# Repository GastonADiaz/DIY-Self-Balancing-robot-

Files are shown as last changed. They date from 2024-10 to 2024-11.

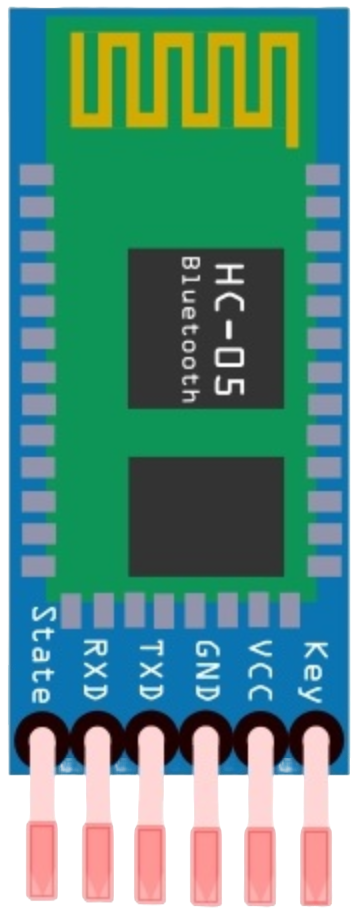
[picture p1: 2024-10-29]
4 - Imagenes para el repositorio/Componentes/hc05.png

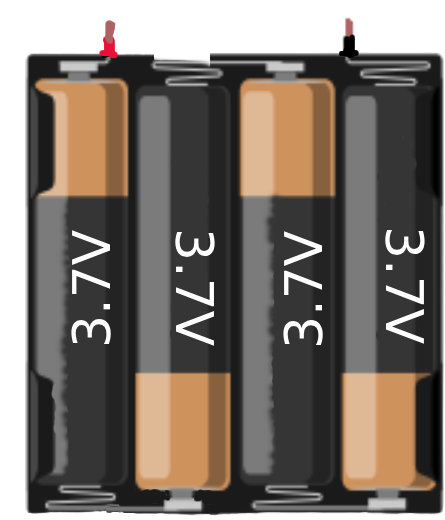
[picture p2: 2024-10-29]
4 - Imagenes para el repositorio/Componentes/4 pilas en serie.png

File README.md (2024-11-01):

# Table of Contents

- 📝 **1.0 [Introduction](#introduction)**
  - **1.1 [Team Members](#Team-Members)**
  - **1.2 [Overview and Objective](#overview-and-objective)**
  - **1.3 [Balancing Robot Working in Real Life](#balancing-robot-working-in-real-life)**
- ⚙️ **2.0 [Components Used](#components-used)**
  - **2.1 [List of Components](#list-of-components)**
  - **2.2 [Principal Tools](#principal-tools)**
  - **2.3 [List of Software Tools](#list-of-software-tools)**
- 🛠️ **3.0 [Mechanical Design](#mechanical-design)**
  -  **3.1 [3D Printed Parts](#3d-printed-parts)**
- ⚡ **4.0 [Electronics](#electronics)**
  -  **4.1 [Overview](#overview)**
  -  **4.2 [Circuit Diagram](#circuit-diagram)**
  -  **4.3 [Wiring Details](#wiring-details)**
  -  **4.4 [PCB Creation with EasyEDA](#pcb-creation-with-easyeda)**
- 💻 **5.0 [Important Code Explanations](#important-code-explanations)**
  - **5.1 [Arduino Nano Connection Pins](#arduino-nano-connection-pins)**
    - **5.1.1 [I2C](#i2c)**
    - **5.1.2 [Motor Driver Pins](#motor-driver-pins)**
  - **5.2 [Configuration](#configuration)**
  - **5.3 [Application Configuration](#application-configuration)**
- ❗ **6.0 [Troubleshooting](#troubleshooting)**
  -  **6.1 [Common Issues and Solutions](#common-issues-and-solutions)**
- 📈 **7.0 [Future Improvements](#future-improvements)**
  -  **7.1 [Potential Add-ons](#potential-add-ons)**
- 📚 **8.0 [Bibliography](#bibliography)**
- 🙏 **9.0 [Acknowledgments](#acknowledgments)**

# Introduction

## Team Members
<p>👤 <a href="https://github.com/GastonADiaz">Gastón Alejandro Díaz</a></p>
<p>👤 <a href="https://github.com/GuillermoDuarte888">Guillermo Daniel Duarte</a></p>

## Overview and Objective

This project addresses the challenge of building a self-balancing robot that maintains its stability in an upright position using two wheels. The robot is based on a series of components, including Nema 17 stepper motors, A4988 motor drivers, an MPU6050 gyro-accelerometer sensor, and an HC-05 Bluetooth module, all managed by an ATmega328p microcontroller.

Additionally, the project incorporates control of the robot via a mobile application. We use the EZ-GUI Ground Station app, typically employed for drones, but we utilize it to manipulate the self-balancing robot through a joystick interface and make custom configurations.

The central objective of this project is to implement a balance control system that allows the robot to remain upright on its own. To achieve this, the system utilizes feedback from the MPU6050 sensor, which measures the tilt angle or "pitch angle." Through a closed-loop control system with a PID (Proportional, Integral, and Derivative) controller, the robot adjusts motor speeds based on the measured angle, correcting any deviations and minimizing balance error. This approach enables the robot to dynamically adapt to variations and effectively maintain its stability.

We would also like to acknowledge the firmware "BalancingWii," which significantly assisted in the development of this project.

## Balancing robot working in real life

In the first video, the balancing robot is shown moving forward, backward, and turning. It is controlled using a mobile application (EZ-GUI Ground Station).

<p align="center">
  first video  
  <br />
  <i>First video in real life</i>
</p>

In the second video,you can see the balancing robot in action. It responds to an external force (in this case, my hands) and demonstrates its ability to maintain balance despite this disturbance. 

<p align="center">
  Second video  
  <br />
  <i>Second video in real life</i>
</p>

# Components Used

## List of Components

| Quantity | Component | Description |
|---|---|---|
| 7 | 3D Printed Parts | 2 wheels, 2 NEMA 17 motor mounts, 3 general structure parts, 4 light diffusers |
| 1 | Perforated Board | For electronics mounting |
| 2 | NEMA 17 Stepper Motors | Motor type used for the robot |
| 1 | MPU6050 | Gyroscope and accelerometer module |
| 2 | A4988 Drivers | Stepper motor drivers |
| 1 | ATmega328p (Arduino Nano) | Microcontroller |
| 1 | 7805T Voltage Regulator | Regulates voltage to 5V |
| 1 | 9V to 12V Power | Rechargeable battery or power supply |
| 1 | On/Off Switch | Power switch |
| 13 | Male Pins | For connecting stepper motor coils to the drivers and LEDs |
| 80 | Female Pins | For connecting various components |
| 1 | 2-Pin Terminal Block | For power connection |
| 2 | Heat Sinks | For cooling the A4988 drivers |
| 2 | 100µF Capacitors | 16V capacitors |
| 2 | 220µF Capacitors | 16V capacitors |
| 8 | XH2.54 Connectors | 2 connectors with 4 pins and 2 connectors with 6 pins for stepper motor wiring |
| 1 | 1 Meter M8 Threaded Rod | For structural support |
| 24 | M8 Hex Nuts | For threaded rod connections |
| 12 | M4 Hex Nuts | For securing components to the structure |
| 12 | M4 Phillips Head Bolts (13mm) | For mounting motor supports and electronics board |
| 8 | M3 Phillips Head Bolts (8mm) | For securing stepper motor mounts |
| 2 | GND and Vin Cables | Power supply cables for the entire circuit |
| 1 | HC-05 Bluetooth Module | For mobile application control |
| 10 | Heat Shrink Tubing | For soldering and joining wires |
| 4 | Green LEDs | For indicating status |
| 4 | 220Ω Resistors | For current limiting on the LEDs |
| 3 | 1kΩ Resistors | For voltage division to provide 3.3V to the RX pin of the HC-05 |
| 4 | Cable Ties | For securing cables |

## Principal Tools

| Quantity | Tool | Description |
|---|---|---|
| 1 | Soldering Iron | For soldering connections |
| 1 | Desoldering Pump | For removing solder |
| 1 | Multimeter (Tester) | For measuring voltage and continuity |
| 1 | Solder wire | For making electrical joints |
| 1 | Screwdriver | For fastening screws |

## List of Software Tools

| Software | Description |
|---|---|
| SolidWorks 2023 | I used SolidWorks 2023 to design the 3D printed parts, model various components, and utilize its toolbox for bolts, nuts, etc. |
| Wokwi | I used Wokwi to create and simulate electronic schematics and code, with the added benefit of simulating without needing physical connections. |
| Arduino IDE | I used Arduino IDE to write and upload the code to the ATmega328p microcontroller. |
| Easy Eda Designer | I used Easy Eda Designer for PCB creation and electronic schematics, as it is a very tidy software for designing PCBs. It allows exporting traces for PCB milling or sending the Gerber file for manufacturing. |
| EZ-GUI Ground Station | I used the EZ-GUI Ground Station APK for mobile control of the robot, allowing manipulation through a joystick interface. |

# Mechanical Design

In this section, I will describe the mechanical design of the robot, including the 3D printed parts and the overall assembly. The designs were created using SolidWorks 2023, which allowed me to visualize the dimensions needed and plan the hardware required, such as screws and other components. The toolbox in SolidWorks also helped in determining the quantity of parts needed and in assembling the pieces to see how everything fits together.

<p align="center">
  All Parts
  <br />
  <i>3D printed parts</i>
</p>

### 3D Printed Parts

1. **Base Plate of the Structure**<br />
  This part is designed to be the base of the balancing robot. It connects with the stepper motors and features 6 holes on each side for screws to secure the NEMA 17 motor mounts. Additionally, there are 4 holes for the 8mm threaded rod that supports the structure.

2. **Support for the NEMA 17 Stepper Motors**<br />
  This piece functions similarly to metal brackets for NEMA 17 motors. However, by printing it, we reduce costs while maintaining the same efficiency for our project. It also includes 2 extra holes compared to standard brackets, allowing for more secure mounting with up to 6 screws.

3. **Central Plate of the Structure**<br />
   This part includes 4 holes for the 8mm threaded rod and 4 additional holes to mount the electronic board. It serves as a key component in securing the electronics in place.

4. **Upper Plate of the Structure**<br />
   This piece is designed to be the top of the robot’s structure. It has 4 holes for the 8mm threaded rod and is a simple yet essential part of the assembly, providing the top support for the robot.
   
5. **Wheels** <br />
   These are the wheel designs used for the robot. Initially, another type of wheel was planned, but this design was chosen for better performance and suitability for the project.

6. **Light Diffusers**  
   The light diffusers are designed to illuminate a LED and are shaped like arrows to indicate the direction of the motor wheels. When both wheels rotate clockwise, the LED will point forward, and when both wheels rotate counterclockwise, the LED will point backward.
   
### Assembly of the Balancing Robot  
   This image shows the overall assembly created in SolidWorks. It combines all the 3D printed parts, demonstrating how they fit together and providing a complete view of the robot's mechanical structure.

<p align="center">
  All Parts  
  <br />
  <i>Rendered in SolidWorks with PhotoView 360</i>
</p>

<p align="center">
  
  <br />
  <i>Assembly animation made with SolidWorks</i>
</p>

# Electronics

## Overview

In this section, I will describe the electronics used in the project. I utilized [Wokwi](https://wokwi.com/) to present the schematic in a more legible and understandable format for anyone. EasyEDA was primarily used to visualize the PCB design, which helped in understanding how the soldering would look and in planning the location of components

## Circuit Diagram

I used Wokwi to create a clear and easy-to-understand schematic diagram. Below is the schematic created using Wokwi (As not all the components are in Wokwi, I had to add it with [photopea](https://www.photopea.com/)):

<p align="center">
  Circuit Diagram
  <br />
  <i>Wokwi connection diagram</i>
</p>

## Wiring Details

The following details explain the purpose of each color used in the wiring connections:

- 🔴 **Red**: Represents the 5V output pin from the ATmega328p.
- ⚫ **Black**: Represents GND.
- 🔵 **Blue**: Represents the microstep pins (MS1, MS2) of the A4988 stepper motor drivers.
- 🟢 **Light Green**: Represents signals from the ATmega328p to control motor steps and direction (STEP and DIR pins of the A4988).
- 🌲 **Dark Green**: Represents a bridge from the SLEEP and DIR pins of the A4988 driver; also used for the positive signal to the LEDs.
- 🌫️ **Gray**: Represents the stepper motor coils (1A, 1B, 2A, 2B).
- 🟦 **Cyan**: Represents I2C communication for the MPU6050.
- 🟠 **Orange**: Represents the power supply (7V, up to 35V).
- 🌸 **Magenta**: Represents 5V output from the 7805T voltage regulator.
- 💛 **Yellow**: Represents the ENABLE pin of the A4988.
- ⚪ **White**: Represents the RX and TX pins of the HC-05.

## PCB Creation with EasyEDA

First, I used **[EasyEDA Designer](https://easyeda.com/es)** to create the overall schematic, connecting the pins of the respective components with their labels to make it more readable. I divided the design into three parts:

1. **Power Supply**: This section includes the circuit necessary to power the Arduino through the **Vin** port, supplying it with 5V.
   
2. **Arduino Nano**: Here, you can find the labels and pins used for the Arduino Nano.

3. **Other Modules**: In the third section, we can see other modules such as the **HC-05**, **MPU6050**, **A4988**, and some male pins that will be used on the board.

<p align="center">
  Esquematico General
  <br />
  <i>Main schematic</i>
</p>

Next, we move on to the PCB creation, where we place the components' locations and the soldering paths for better organization when creating it in real life. In the following image, we can see the soldering paths from the top view (Red color 🔴)  as well as the bottom view (Blue color 🔵). There are also measurement dimensions in case anyone is interested in replicating it.

<p align="center">
  PCB Full
  <br />
  <i>PCB with measurements and both solder paths fused</i>
</p>

Finally, here is how a printed circuit board would look, both from the top and bottom views. I did not include 3D components because I prefer to show the silkscreen.

<p align="center">
  PCB_Superior_e_Inferior
  <br />
  <i>PCB Top and Bottom View</i>
</p>

In the following GIF, you can see the components and the 3D PCB layout that were created in EasyEDA. It also features functionalities such as changing the color of the board and the option to hide or show the components, among other capabilities. This representation is essentially our actual board, but with a perforated design.

<p align="center">
  PCB en vista 3D
  <br />
  <i>PCB visualized in 3D with EasyEDA</i>
</p>

# Important code explanations

## Arduino Nano Connection Pins

### I2C:
- A4 - SDA
- A5 - SCL

```
#define I2C_PULLUPS_ENABLE         PORTC |= 1<<4; PORTC |= 1<<5;   // PIN A4 & A5 (SDA & SCL)
```

### Motor Driver Pins:
- D5 - STEP1 (PORTD 5)
- D6 - STEP2 (PORTD 6)
- D7 - DIR1 (PORTD 7)
- D8 - DIR2 (PORTB 0)
- D4 - ENABLE (for both)
  
```
uint8_t DRIVER_PIN[5] = {5, 6, 7, 8, 4};   // STEP1 (PORTD 5), STEP2 (PORTD 6), DIR1 (PORTD 7), DIR2 (PORTB 0), ENABLE
```
## Configuration

These are the optional settings you can modify for each balancing robot in the `config.h` file:

The first important configuration is the orientation of the MPU6050. You can change this in this section by setting it to either "ROLL" or "PITCH." In my case, I use "PITCH."

```
#define CURRENT_AXIS    PITCH       // it is possible to choose ROLL or PITCH axis as current.
```

Another crucial setting for the balancing robot is the adjustment of values based on its performance. Comments indicate typical values that usually work well:

```
#define MAX_SPEED           350    // should be <= 500 // Con 350 va bien 
#define MAX_TARGET_ANGLE    130    // where 10 = 1 degree, should be <= 15 degree (i.e. <= 150) 
#define MAX_STEERING        90     // should be <= 100

#define RISE_SPEED_K        1.0f   // this coefficient means how faster robot will be during the auto rising...  should be >= 0.5 but <= 2.0
```

Another configuration pertains to the HC-05 Bluetooth module. To use it, it must be set to a baud rate of 115200, as shown in the following lines of code:

```
#define SERIAL0_COM_SPEED 115200
#define SERIAL1_COM_SPEED 115200
#define SERIAL2_COM_SPEED 115200
#define SERIAL3_COM_SPEED 115200
```

By default, Bluetooth modules come configured to 9600 baud. To change this, you need to enter the following command in the serial terminal while the module is in AT mode :
```
AT+UART=115200,0,0
```
If for any reason you need to modify how the left and right motors are managed, you can do so in the Interrupt Service Routine (ISR) located in `Output.cpp`. This ISR is responsible for controlling the STEP and DIR signals for both motors.

The ISR is defined as follows:
```
ISR(TIMER1_COMPA_vect) {
}
```

# Application Configuration

As mentioned in another section of this README, we will be using the [EZ-GUI Ground Station application](https://ez-gui-ground-station.uptodown.com/android), which can be downloaded from Google .

The first time you install the application, it will prompt you to enable Bluetooth and location services; make sure to allow both.

<p align="center">
  Primera imagen Ez-Gui
  <br />
  <i>first steps to follow</i>
</p>

Once that is done, go to the three dots in the upper right corner and select "Settings." In this section, choose the Bluetooth module HC-05. After selecting it, click the "Next" button.

Next, select the "Multiwii 2.40" firmware from the list and keep clicking "Next" until you reach the home screen.

Once everything is configured, click the "Connect" button. After connecting, swipe the screen to the right to see the following:

<p align="center">
  Menu de opciones
  <br />
  <i>options menu</i>
</p>

Then, press the "AUX" option and check all the boxes in the following settings. After doing this, click the upload button (the red arrow pointing upwards).

<p align="center">
  AUX
  <br />
  <i>AUX option</i>
</p>

Next, go back and click on the "PID" button. I recommend using the following values if you are using the same design and wheels as I am, as each robot behaves differently. A smaller robot might require different PID values, just as a larger robot with bigger wheels would.

As before, upload the values to the Arduino using the red arrow button.

<p align="center">
  PID
  <br />
  <i>PID option</i>
</p>

The last option is for calibrating the MPU6050. For this, the wheels of your balancing robot must be stationary, and the robot should be perfectly vertical on a flat surface. When you press the "Calibration" button, wait about 10 to 15 seconds for it to complete the gyroscope and accelerometer calibration process.

Finally, you can start using your balancing robot by going back from this screen, clicking on the three dots in the top right corner, selecting "Advanced," then "Untested," and finally clicking on "Model Control."

<p align="center">
  joystick
  <br />
  <i>joystick</i>
</p>

>[!NOTE]
>To stop the wheels, use [MID] in the first option. Use [ARM] to turn the wheels on.

In the third option, you can also experiment with the different settings available in the application, and you have the joystick to control the balancing robot.

# Troubleshooting

## Common Issues and Solutions

**1. Wheel Slipperiness:**
   
One of the main challenges encountered in this project was related to the wheels. The 3D-printed wheels were very slippery on certain surfaces, such as ceramic and wood.

**Solution:**
To enhance grip and friction, we added strips of EVA rubber around the entire perimeter of the wheels. This significantly improved the wheel's traction on slippery surfaces.

<p align="center">
  
  <br />
  <i>wheels with EVA rubber</i>
</p>

**2. Wheel Attachment Stability:**
   
Another issue with the wheels was that the screws used to attach them were insufficient. Over time, vibrations from the motor caused the screws to loosen and come out.

<p align="center">
  
  <br />
  <i>After a long time, the wheels would gradually come off due to the vibrations of the motors.</i>
</p>

**Solution:**
To resolve this, we applied adhesive to secure the axle parts. This greatly improved stability, and the wheels no longer detached.

**3. A4988 Driver Potentiometer Adjustment:**

Another issue was related to the potentiometer on the A4988 driver. When set to a low level (around 0.2V), the wheels would barely move, especially under load.

**Solution:**
By adjusting the potentiometer to approximately 1V, we found that both wheels operated smoothly, resolving the issue of the wheels stalling when they encountered resistance. This adjustment made a significant difference in performance.

<p align="center">
  
  <br />
  <i>Adjustment of the A4988 driver potentiometer</i>
</p>

**4. Bluetooth Module Connection During Upload:**

When uploading code to the Arduino Nano, the Bluetooth module must be disconnected. This is necessary because the module uses the RX and TX pins of the Arduino for communication.

**Solution:**
When you upload code, the Arduino needs exclusive access to the RX (receive) and TX (transmit) pins to communicate with the computer. If the Bluetooth module is connected, it may interfere with this process, preventing the upload from completing successfully. To ensure a smooth upload, always disconnect the Bluetooth module before loading new code onto the Arduino Nano.

# Future Improvements

##  Potential Add-ons

I. **18650 Battery Power Source:**
   Incorporating 18650 batteries as a power source could enhance the robot's mobility. In my case, I currently use a 12V power supply, as the batteries are quite expensive in my country. The batteries would allow for greater freedom of movement without the risk of cables tangling during turns.

II. **Camera Integration:**
   Adding a camera to the balancing robot would enable remote observation, as if the robot were exploring areas. This feature could facilitate mapping of environments.

III. **Ultrasonic Sensor Module:**
   Integrating an ultrasonic sensor would help the robot avoid collisions with walls or obstacles, enhancing its navigation capabilities.

IV. **Improved Printed Circuit Board (PCB):**
   While I initially used a perforated board, there are PDF files available for creating a more professional-looking PCB using either the marker or toner transfer methods. Additionally, you could consider sending the design to a manufacturer like PCBWay or other reputable providers.

V. **Custom Software Development:**
   Creating a complete application and software from scratch, without relying on existing libraries or pre-made applications, would be a significant undertaking. However, the current setup provides a solid foundation for such an endeavor.

# Bibliography

All the references used in the development of this project will be compiled in a text file, which will include all the links we utilized as guides throughout the process.

# Acknowledgments

I would like to extend my sincere gratitude to several individuals and organizations for this project.

- **Guillermo Daniel Duarte**: A special thank you to my colleague for his invaluable assistance and support throughout this project. Your help was crucial to its completion.

- **Professor Cristian Leandro Lukasiewicz**: I am deeply grateful to Professor Lukasiewicz for overseeing our Supervised Professional Practice (PPS) and providing guidance and support throughout the process.

- **National University of Lomas de Zamora, Faculty of Engineering**: For opening the doors to a rich academic environment that has allowed me to pursue my studies and acquire valuable knowledge.

- **Mahowik**: A heartfelt thanks to Mahowik for the fantastic firmware provided in the [BalancingWii](https://github.com/mahowik/BalancingWii). Your work has greatly contributed to the success of this project.

- **To all readers**: I hope you find this project both interesting and useful.

Logo facultad con color

<div align="center">

<b><i>Best regards, and have a great day!</i></b>

</div>

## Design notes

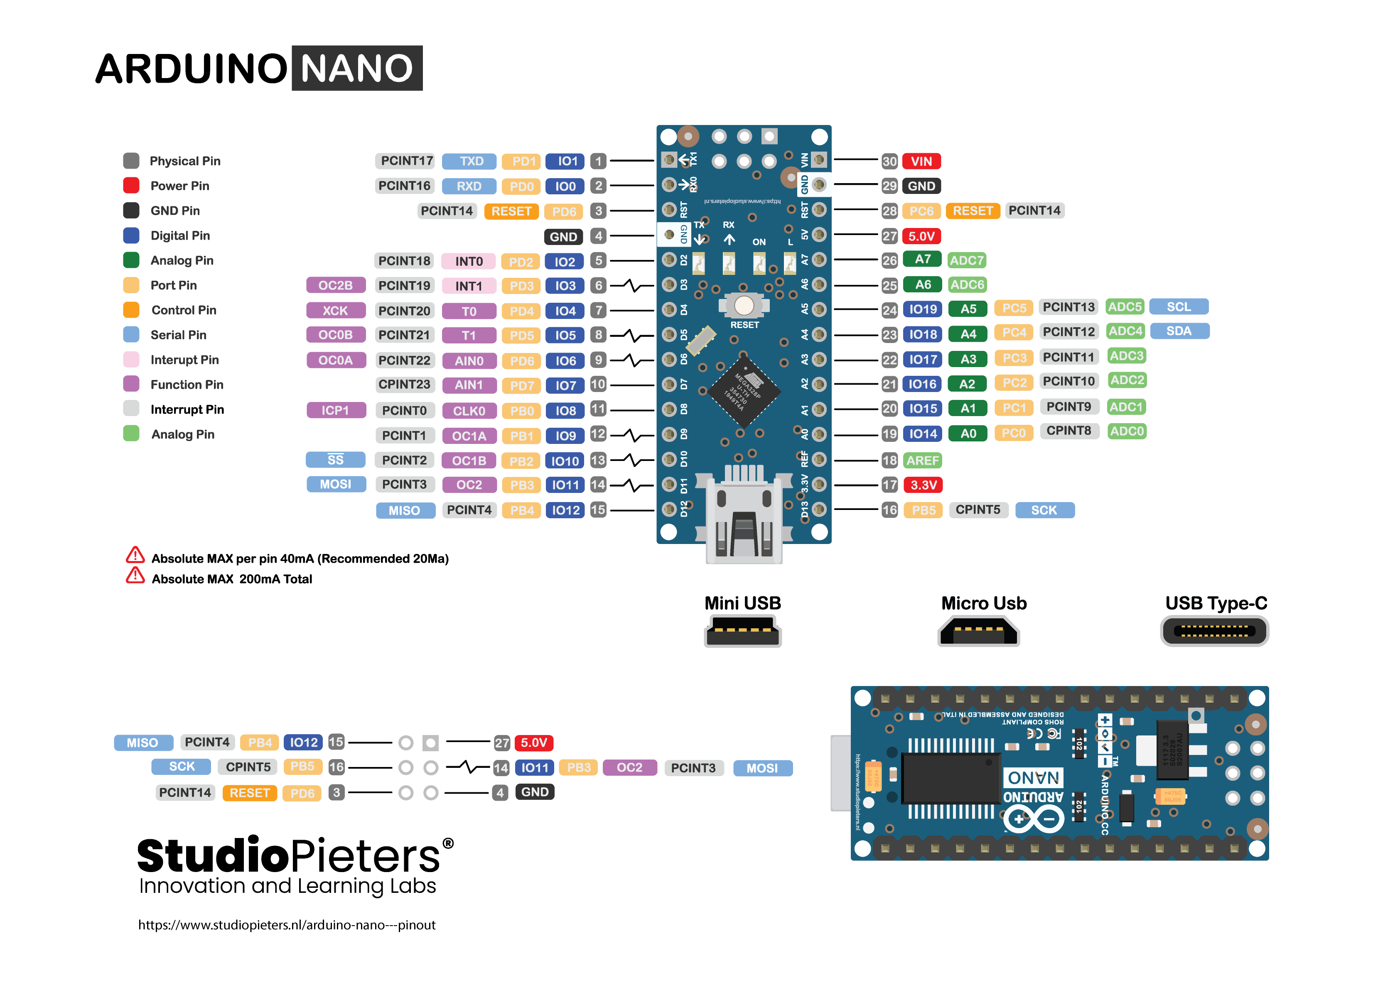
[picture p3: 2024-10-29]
4 - Imagenes para el repositorio/Componentes/Arduino-Pinout.png

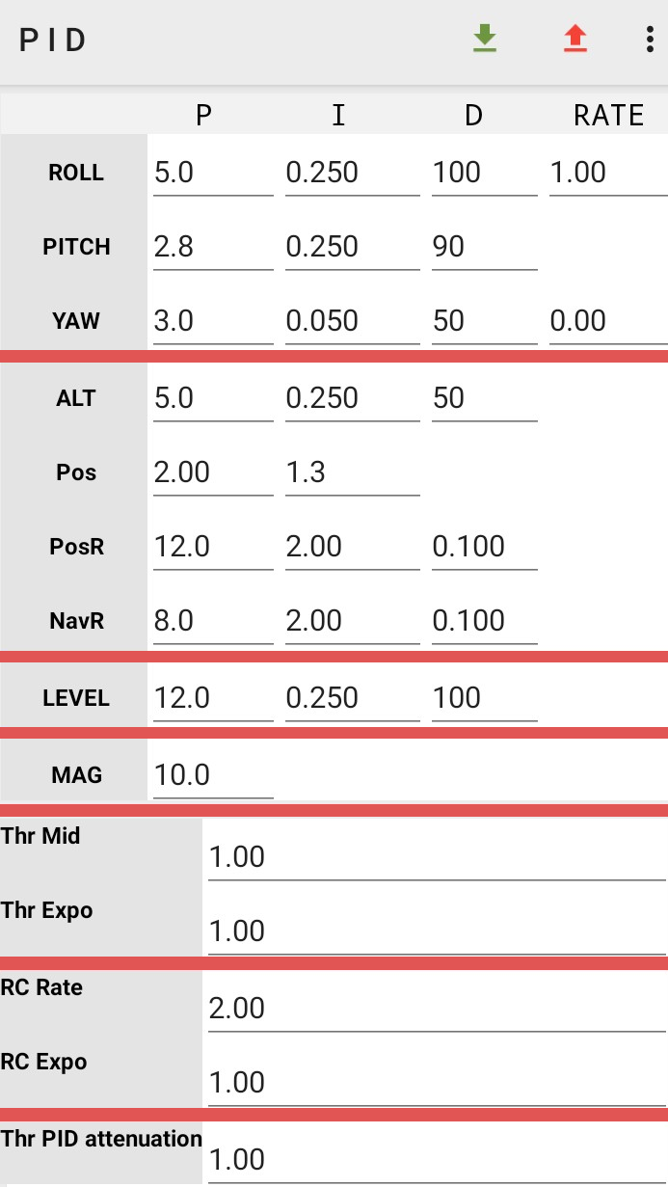
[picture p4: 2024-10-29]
4 - Imagenes para el repositorio/PID.png

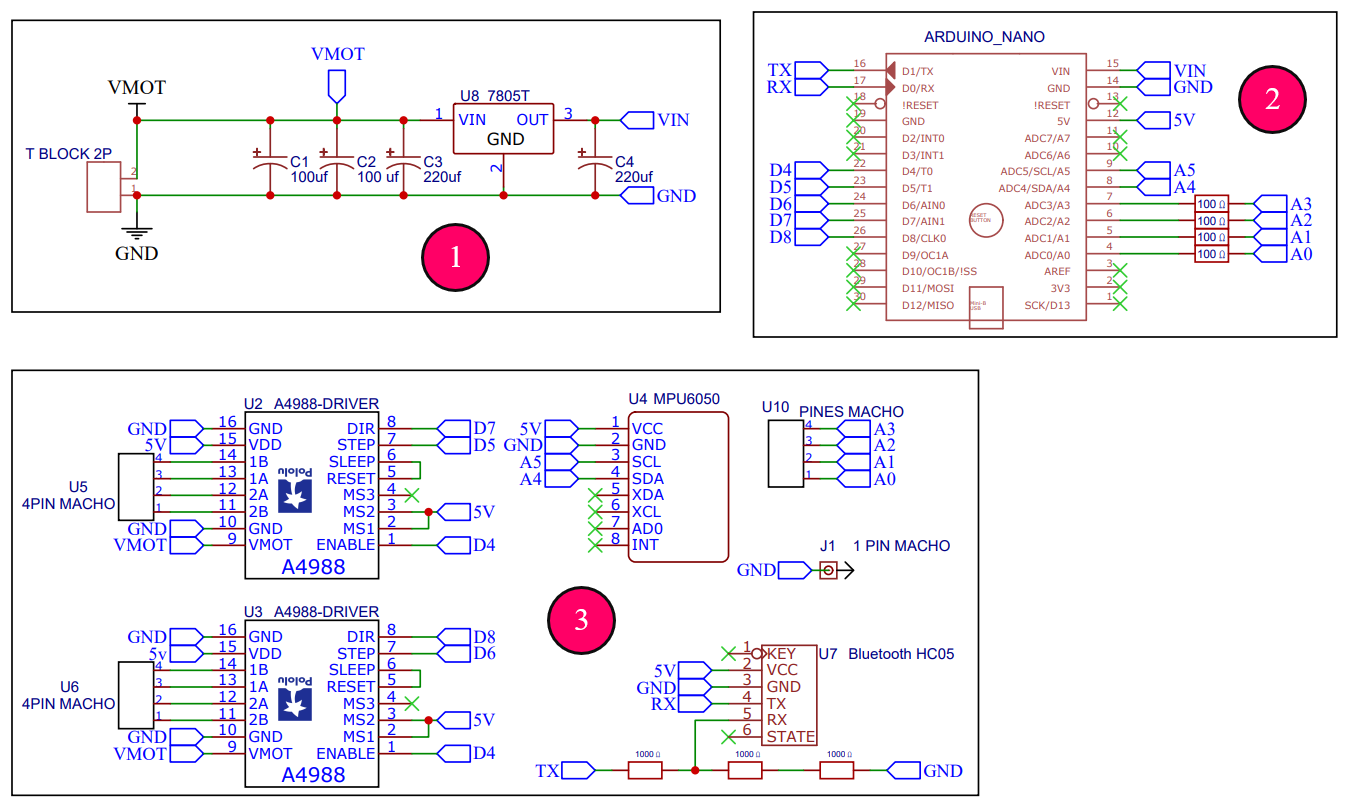
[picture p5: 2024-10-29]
4 - Imagenes para el repositorio/Esquematico_General (1).png

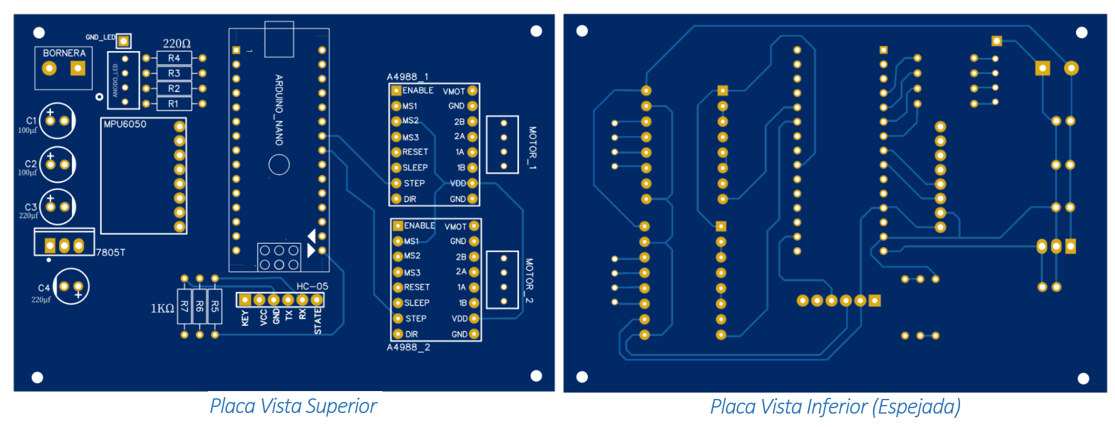
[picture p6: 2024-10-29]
4 - Imagenes para el repositorio/Placa Vista Superior e Inferior.png

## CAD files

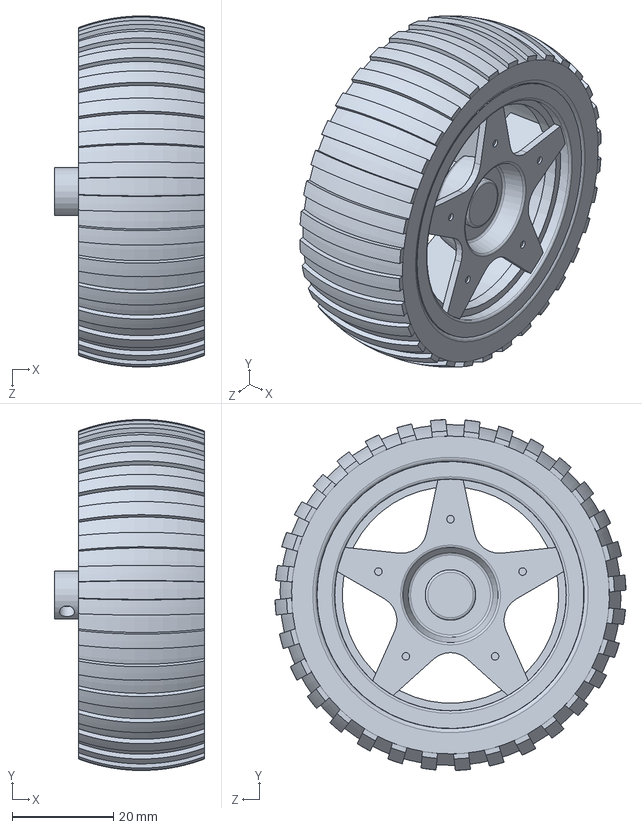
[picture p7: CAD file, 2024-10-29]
1 - Piezas solidworks/Ensamblaje de Rueda.SLDPRT
29.8 x 69.5 x 69.5 mm

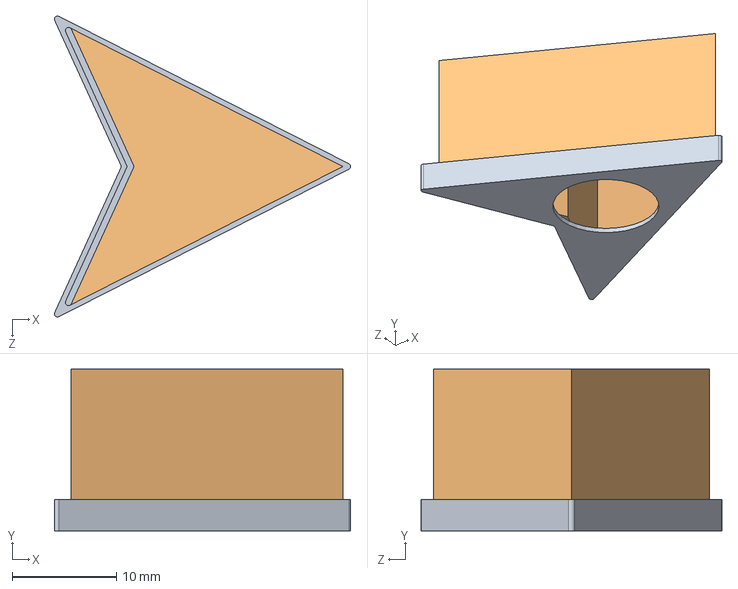
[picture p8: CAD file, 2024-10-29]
1 - Piezas solidworks/Ensamblaje para difusor de luz.SLDASM
28.4 x 15.5 x 28.8 mm
Pieza11 - Difusor de luz 20mm
Pieza12 - Encaje difusor de luz 20mm

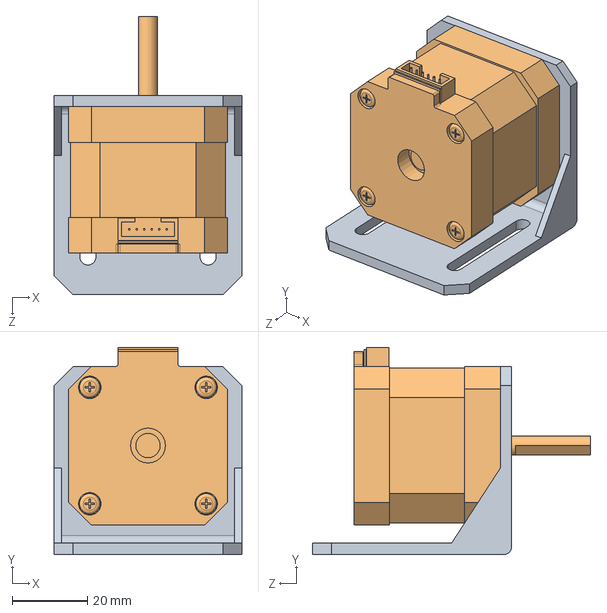
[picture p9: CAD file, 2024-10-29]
1 - Piezas solidworks/Ensamblaje Motor nema 17 con soporte.SLDASM
50.0 x 55.1 x 74.0 mm
Pieza 4 - Soporte de motor paso a paso Nema 17
Pieza 5 - Motor paso a paso Nema 17

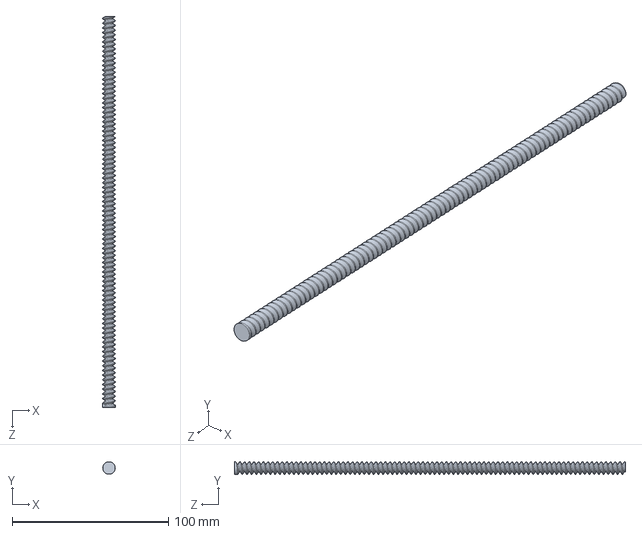
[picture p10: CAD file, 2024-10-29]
1 - Piezas solidworks/Pieza 6 - Varilla roscada.SLDPRT
8.00 x 8.00 x 250.0 mm

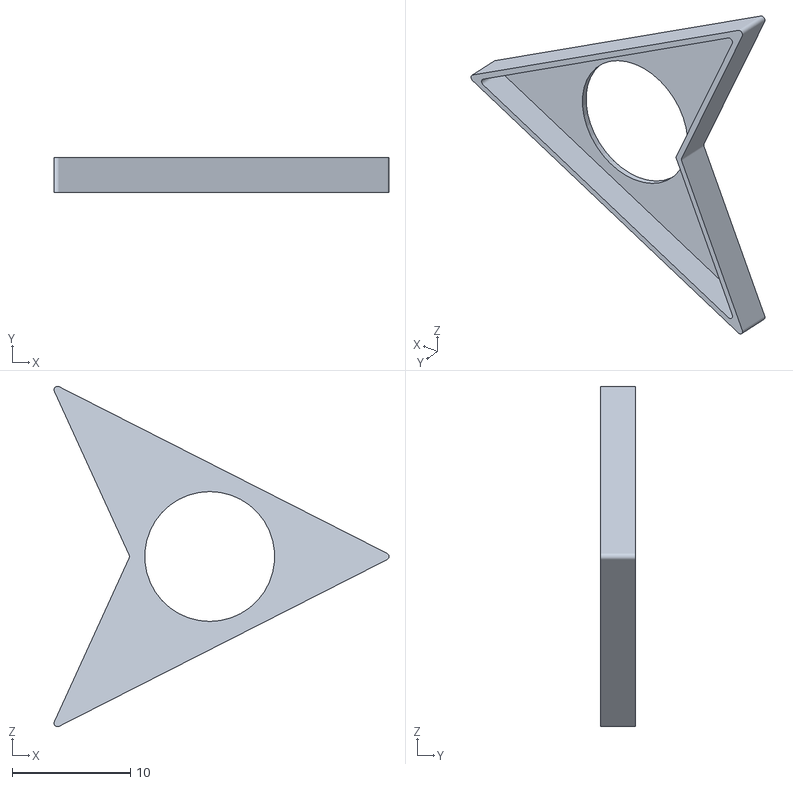
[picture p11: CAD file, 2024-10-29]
1 - Piezas solidworks/Piezas para imprimir/Piezas en STL/Pieza12 - Encaje difusor de luz 20mm.STL
28.4 x 3.00 x 28.8

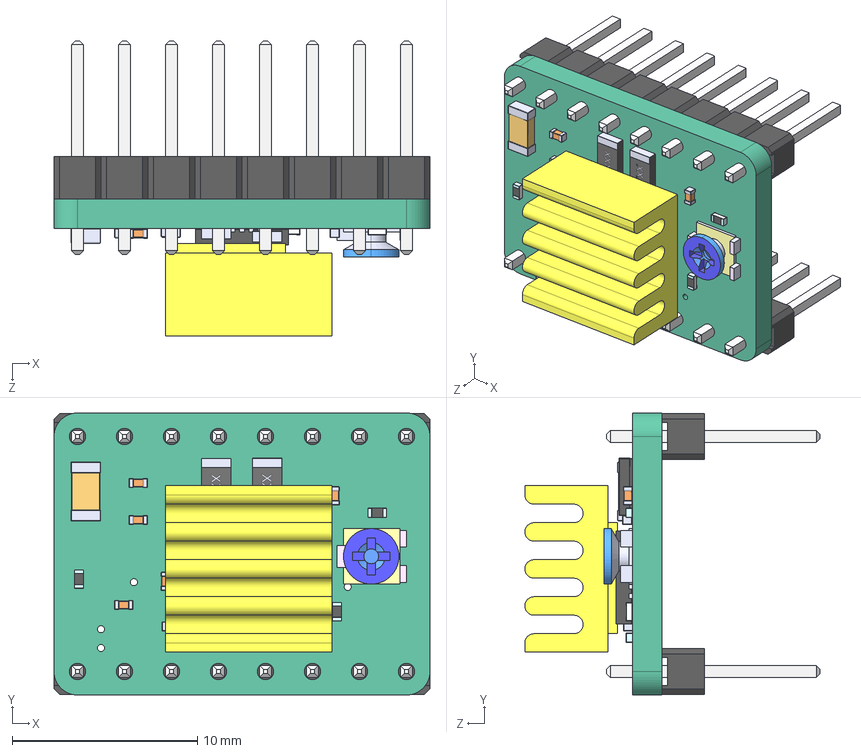
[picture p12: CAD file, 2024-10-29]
2 - PCB en proteus (Para ESP32S)/apariencias para proteus/A4988-1.STEP
20.3 x 15.2 x 16.0 mm
stepstick
QFN28ET_A4983
TRIMPOT3MM_TRIMPOTSMD
Pin header pitch 2.54mm_08 contacts x 2
Heatsink For A4988
R0402-01 x 4
R1206-01 x 2
C0402 x 6
C1206B

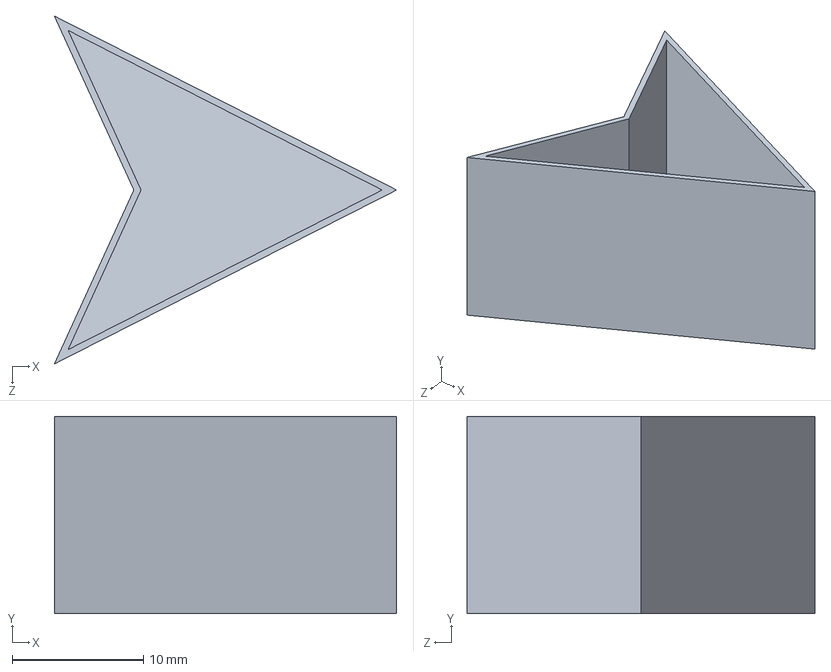
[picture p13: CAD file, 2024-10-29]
1 - Piezas solidworks/Pieza11 - Difusor de luz 20mm.SLDPRT
26.0 x 15.0 x 26.5 mm

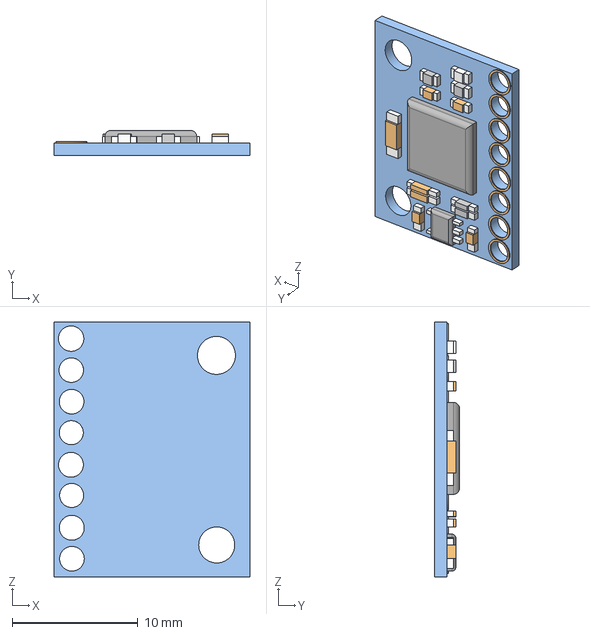
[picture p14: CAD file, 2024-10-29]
2 - PCB en proteus (Para ESP32S)/apariencias para proteus/MPU6050 v2.step
15.6 x 2.00 x 20.3 mm

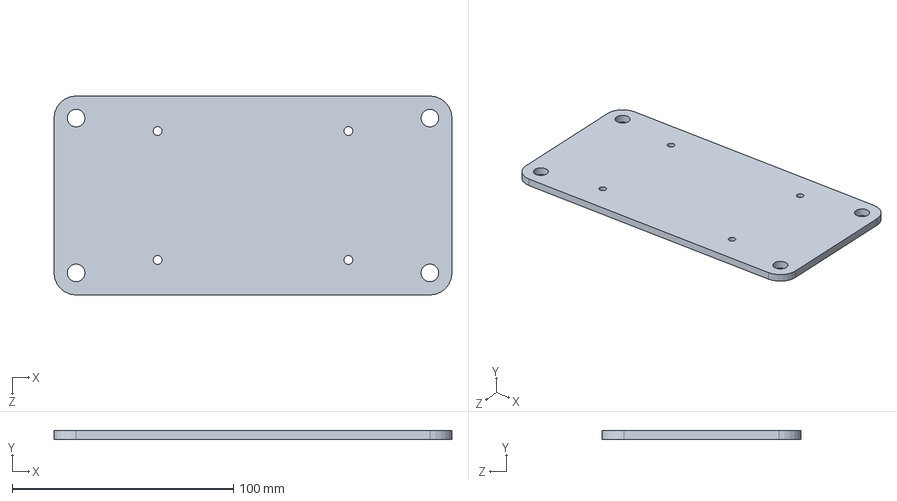
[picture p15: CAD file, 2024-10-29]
1 - Piezas solidworks/Pieza 7 - Placa central de la estructura general.SLDPRT
180.0 x 4.00 x 90.0 mm

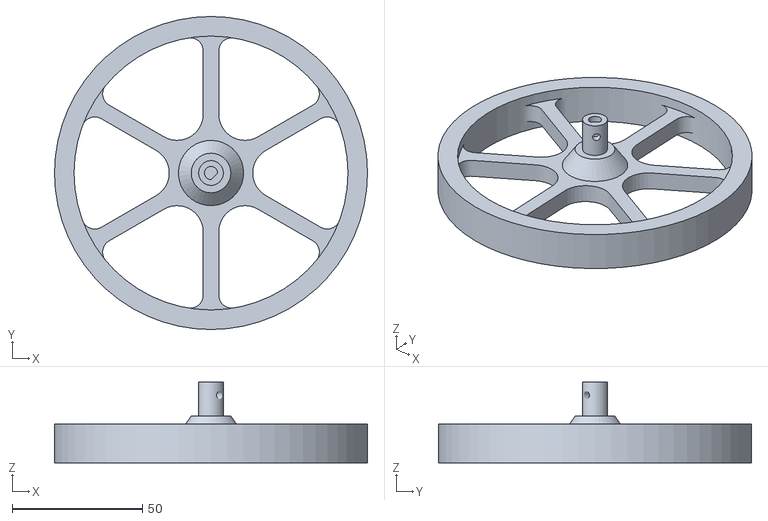
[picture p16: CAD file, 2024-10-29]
1 - Piezas solidworks/Piezas para imprimir/Piezas en STL/Pieza 10 - Rueda simple.STL
120.0 x 120.0 x 31.0

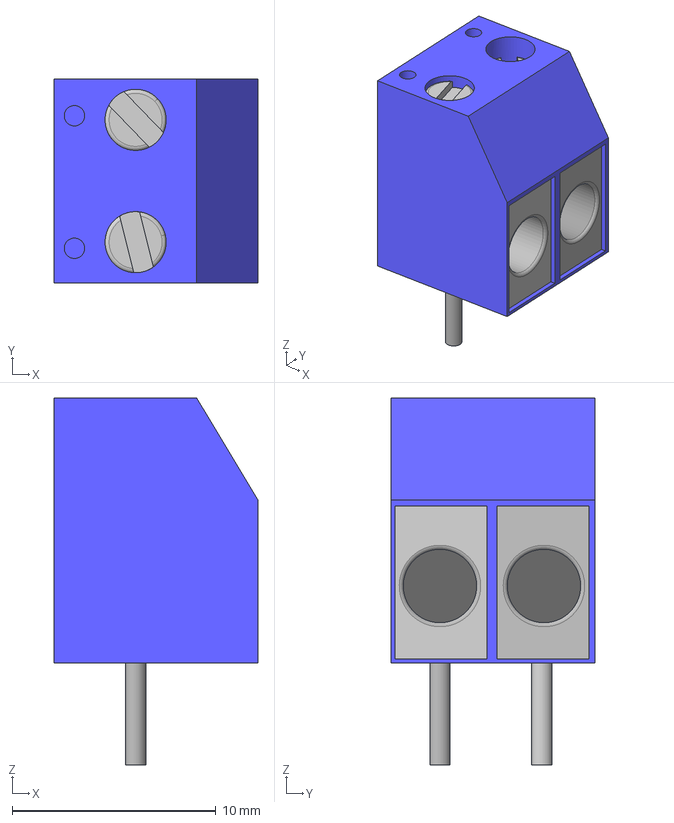
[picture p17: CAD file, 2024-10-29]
2 - PCB en proteus (Para ESP32S)/apariencias para proteus/borneraazul2pines.step
10.0 x 10.0 x 18.0 mm

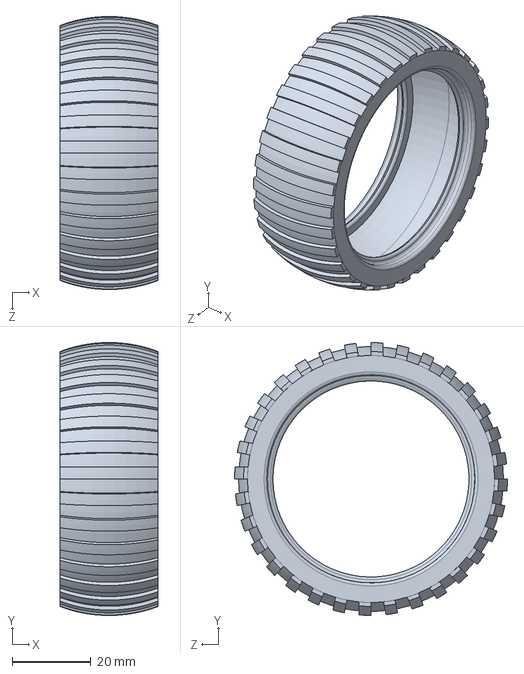
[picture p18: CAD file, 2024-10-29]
1 - Piezas solidworks/Pieza 3 - Goma de rueda.SLDPRT
25.0 x 69.5 x 69.5 mm

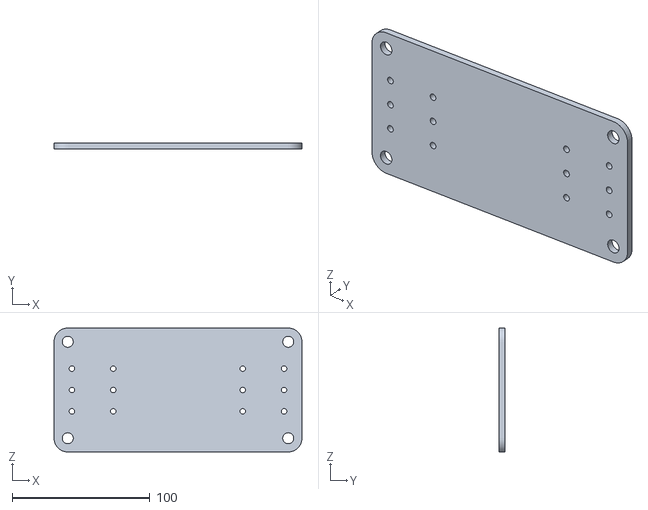
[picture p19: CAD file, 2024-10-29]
1 - Piezas solidworks/Piezas para imprimir/Piezas en STL/Pieza 1 - Placa inferior de la estructura general.STL
180.0 x 4.00 x 90.0

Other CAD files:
1 - Piezas solidworks/Piezas para imprimir/Piezas en STL/Pieza11 - Difusor de luz 20mm.STL
1 - Piezas solidworks/Pieza 9 - Placa superior de la estructura general.SLDPRT
1 - Piezas solidworks/Piezas para imprimir/Piezas en STL/Pieza 7 - Placa central de la estructura general.STL
1 - Piezas solidworks/Pieza12 - Encaje difusor de luz 20mm.SLDPRT
1 - Piezas solidworks/Piezas para imprimir/Piezas en STL/Pieza 9 - Placa superior de la estructura general.STL
1 - Piezas solidworks/Pieza 0 - Piso.SLDPRT
1 - Piezas solidworks/Pieza 1 - Placa inferior de la estructura general.SLDPRT
1 - Piezas solidworks/Pieza 10 - Rueda simple.SLDPRT
1 - Piezas solidworks/Pieza 2 - Rin de rueda.SLDPRT
1 - Piezas solidworks/Pieza 4 - Soporte de motor paso a paso Nema 17.SLDPRT
1 - Piezas solidworks/Pieza 5 - Motor paso a paso Nema 17 .SLDPRT
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

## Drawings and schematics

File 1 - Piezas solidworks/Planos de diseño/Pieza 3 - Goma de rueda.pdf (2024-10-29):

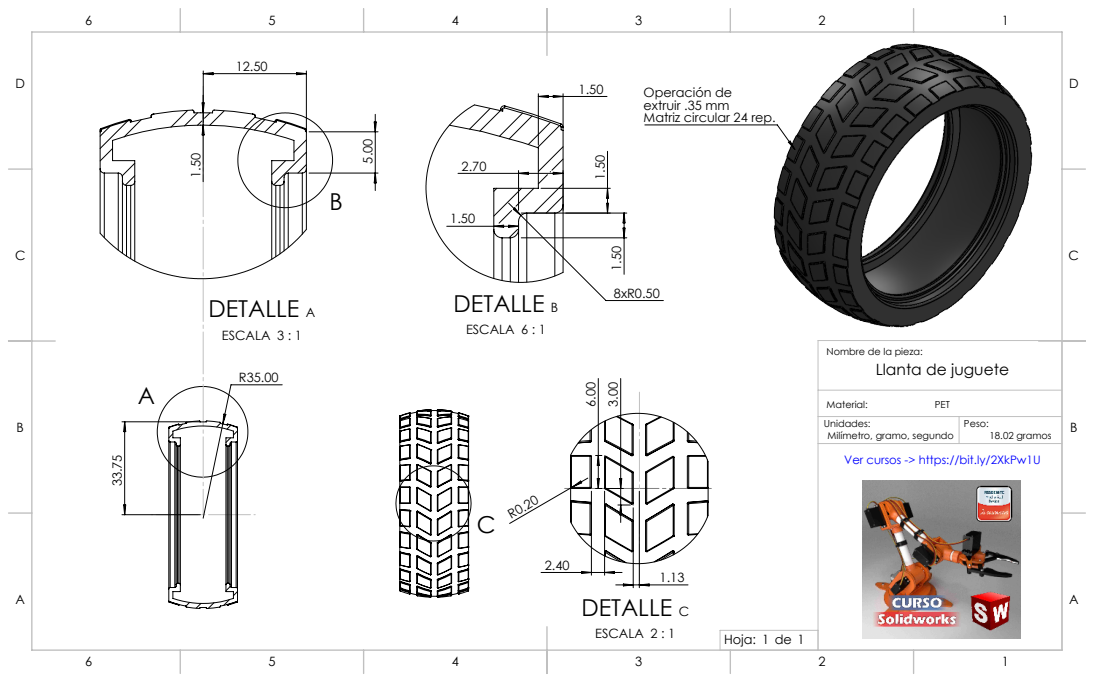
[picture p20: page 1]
DETALLE A; ESCALA 3 : 1; 8xR0.50 DETALLE B; ESCALA 6 : 1; DETALLE C; ESCALA 2 : 1; 18.02 gramos; Hoja: 1 de 1

Operación de
extruir .35 mm
Matriz circular 24 rep.

Nombre de la pieza:
Llanta de juguete

Milímetro, gramo, segundo
Ver cursos -> https://bit.ly/2XkPw1U

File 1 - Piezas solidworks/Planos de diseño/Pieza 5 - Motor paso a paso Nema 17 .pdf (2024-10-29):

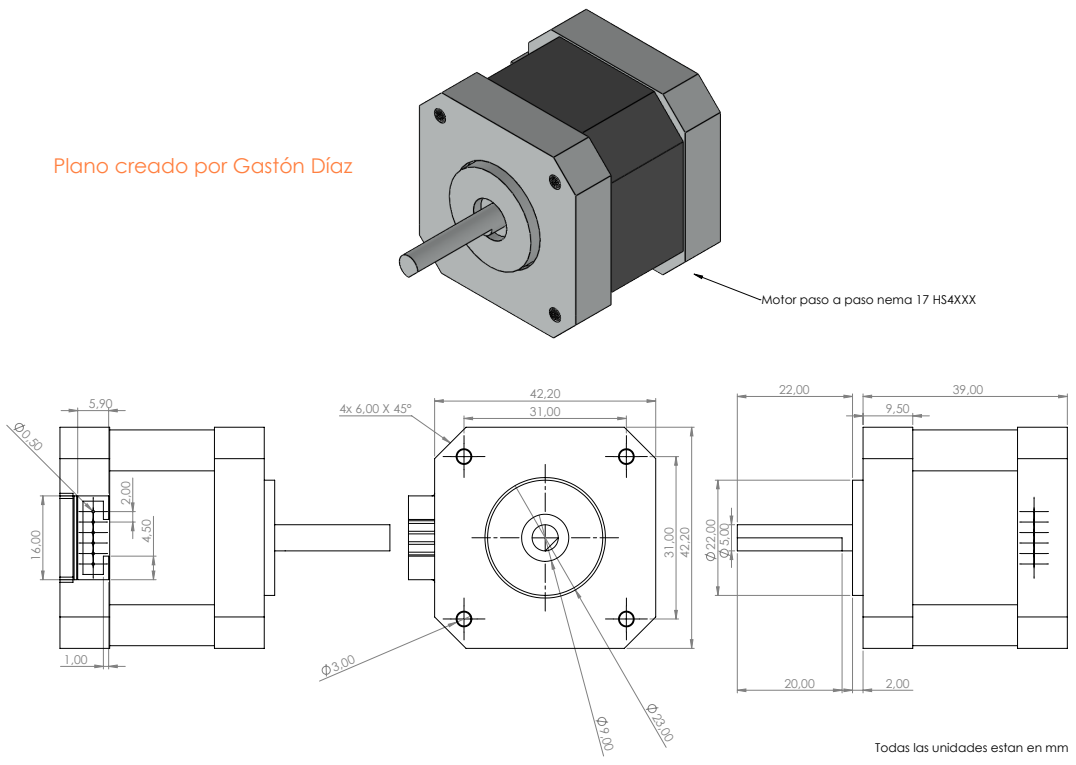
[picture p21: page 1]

Plano creado por Gastón Díaz

Motor paso a paso nema 17 HS4XXX

Todas las unidades estan en mm

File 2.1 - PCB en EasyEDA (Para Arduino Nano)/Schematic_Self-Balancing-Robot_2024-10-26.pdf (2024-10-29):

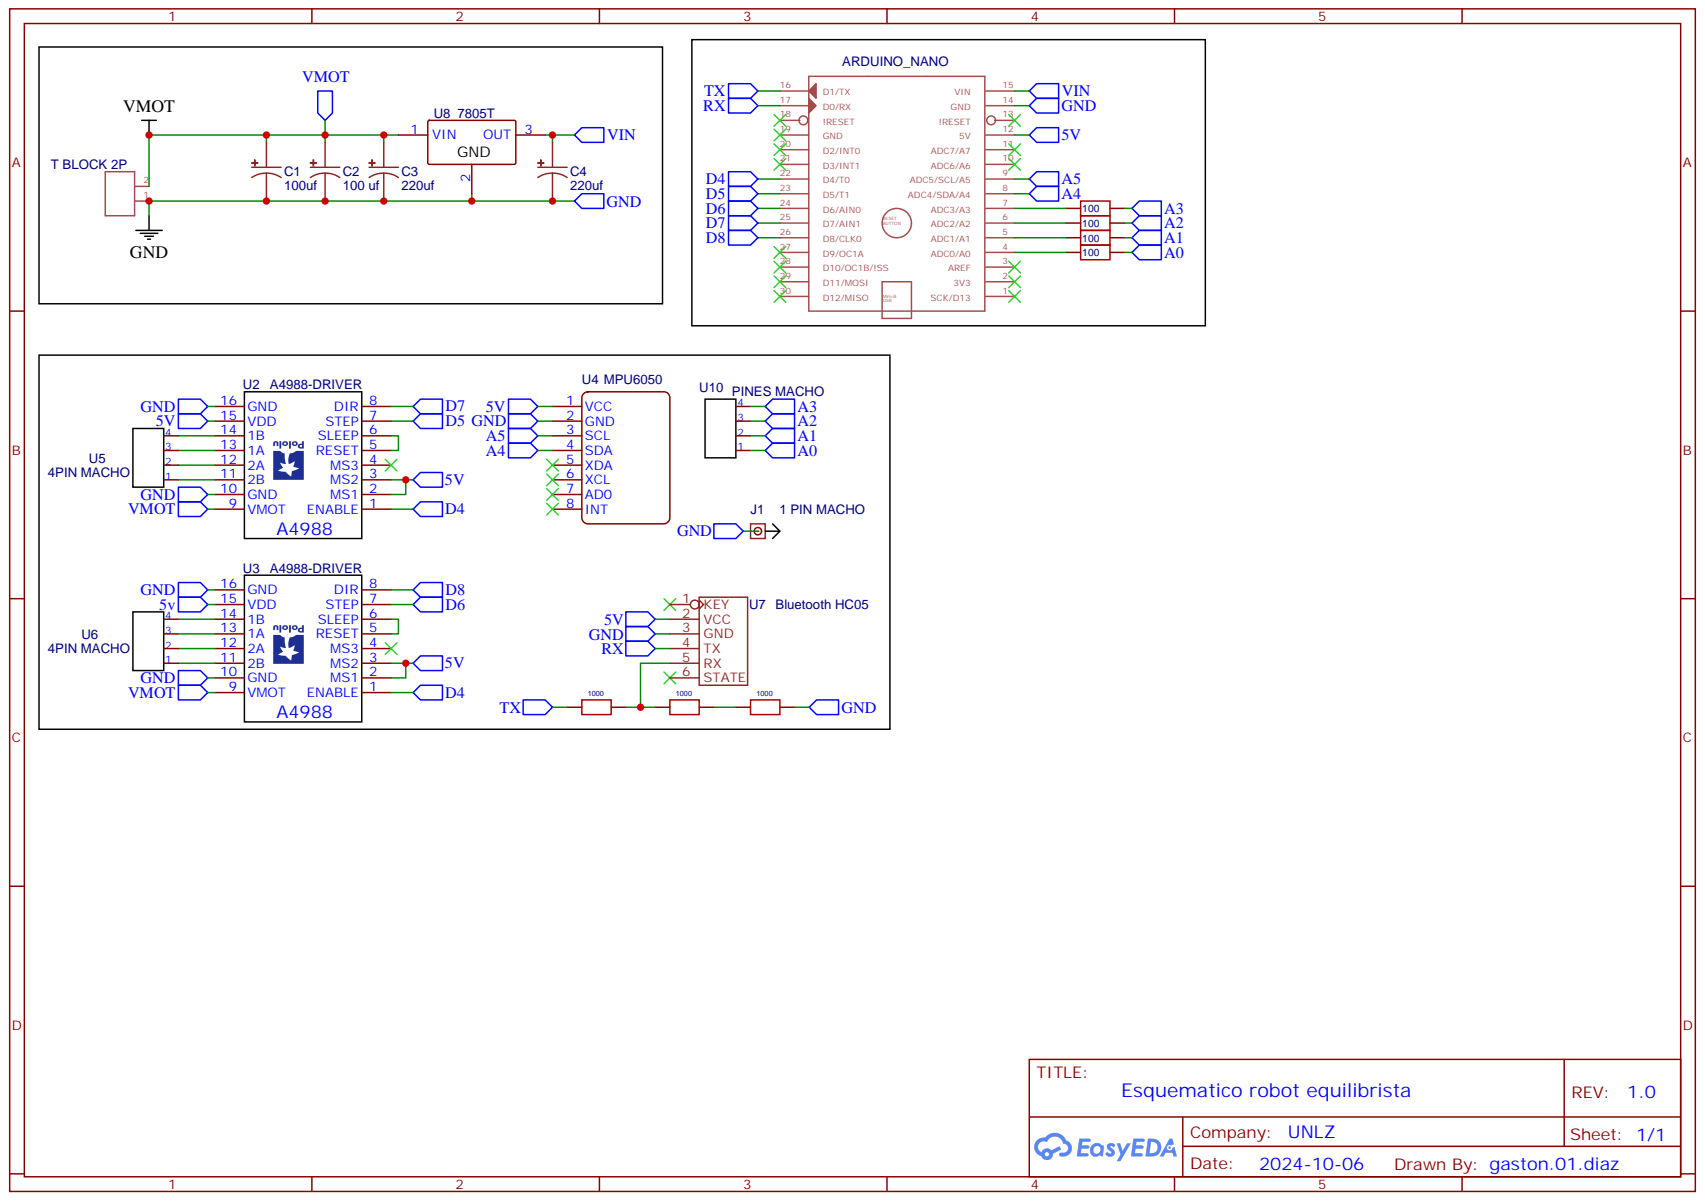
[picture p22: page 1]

Drawn By: gaston.01.diaz

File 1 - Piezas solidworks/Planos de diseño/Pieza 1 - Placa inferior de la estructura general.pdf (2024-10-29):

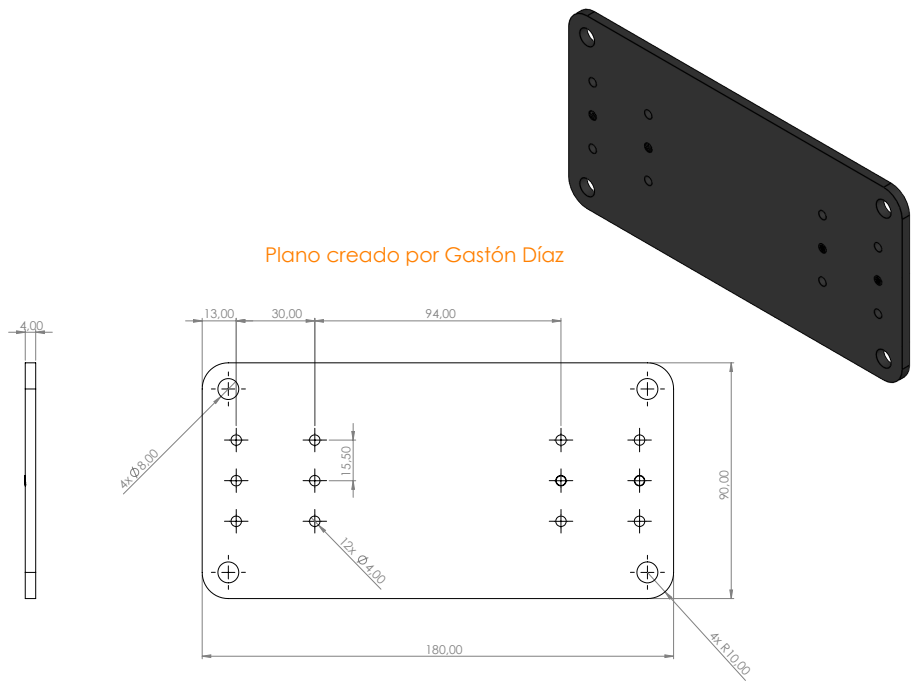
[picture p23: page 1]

Plano creado por Gastón Díaz

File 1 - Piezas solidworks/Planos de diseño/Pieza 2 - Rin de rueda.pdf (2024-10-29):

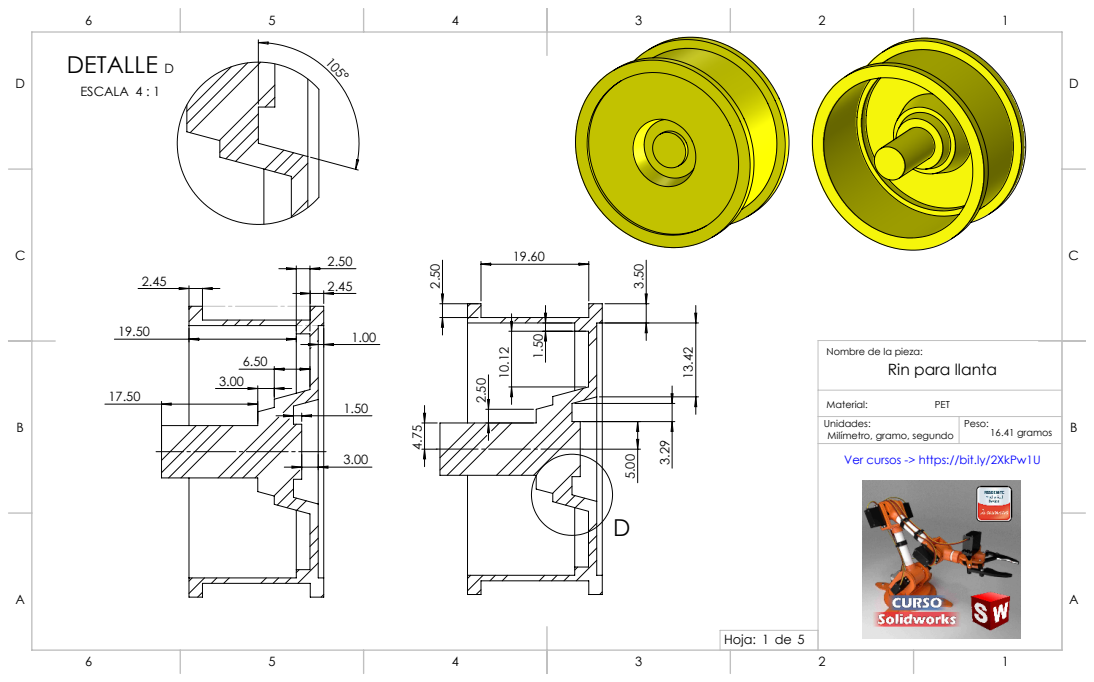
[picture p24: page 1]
DETALLE D; ESCALA 4 : 1; Hoja: 1 de 5; 16.41 gramos

Nombre de la pieza:
Rin para llanta

Milímetro, gramo, segundo
Ver cursos -> https://bit.ly/2XkPw1U

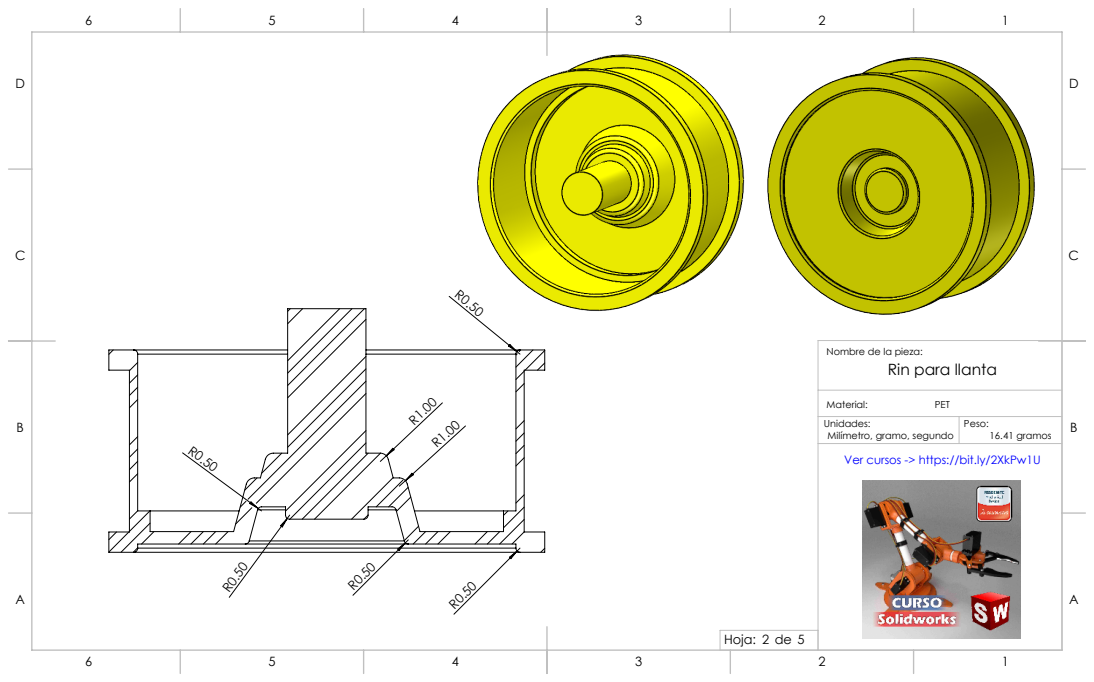
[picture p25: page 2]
16.41 gramos

Nombre de la pieza:
Rin para llanta

Milímetro, gramo, segundo
Ver cursos -> https://bit.ly/2XkPw1U

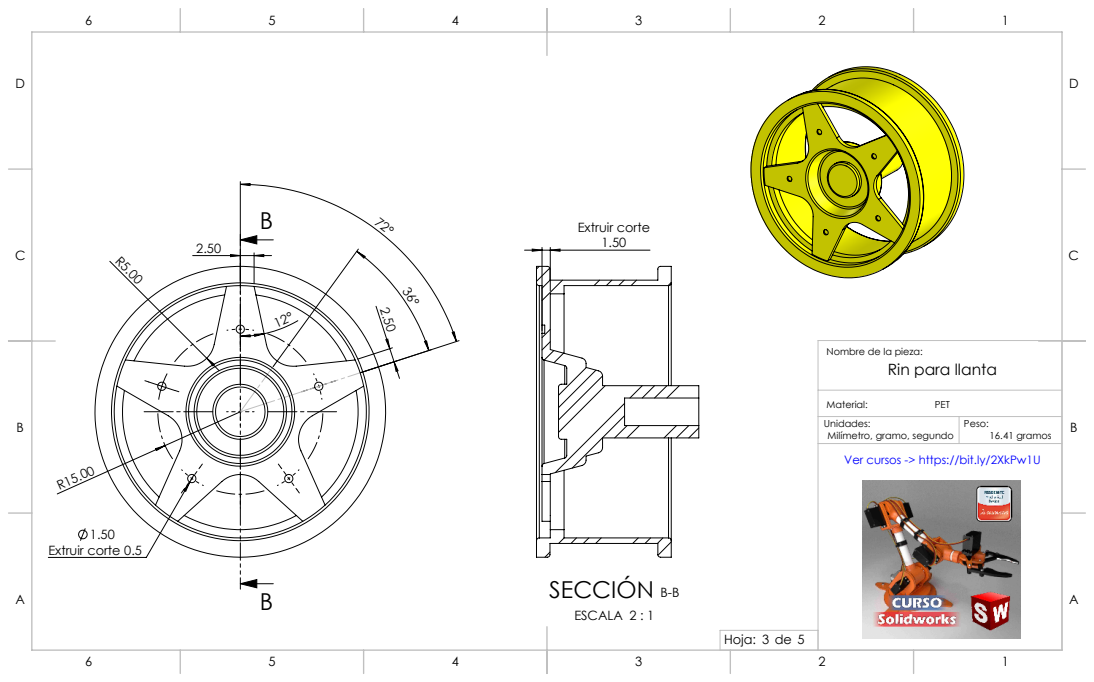
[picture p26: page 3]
Extruir corte 0.5; Extruir corte; SECCIÓN B-B; ESCALA 2 : 1; 16.41 gramos

Nombre de la pieza:
Rin para llanta

Milímetro, gramo, segundo
Ver cursos -> https://bit.ly/2XkPw1U

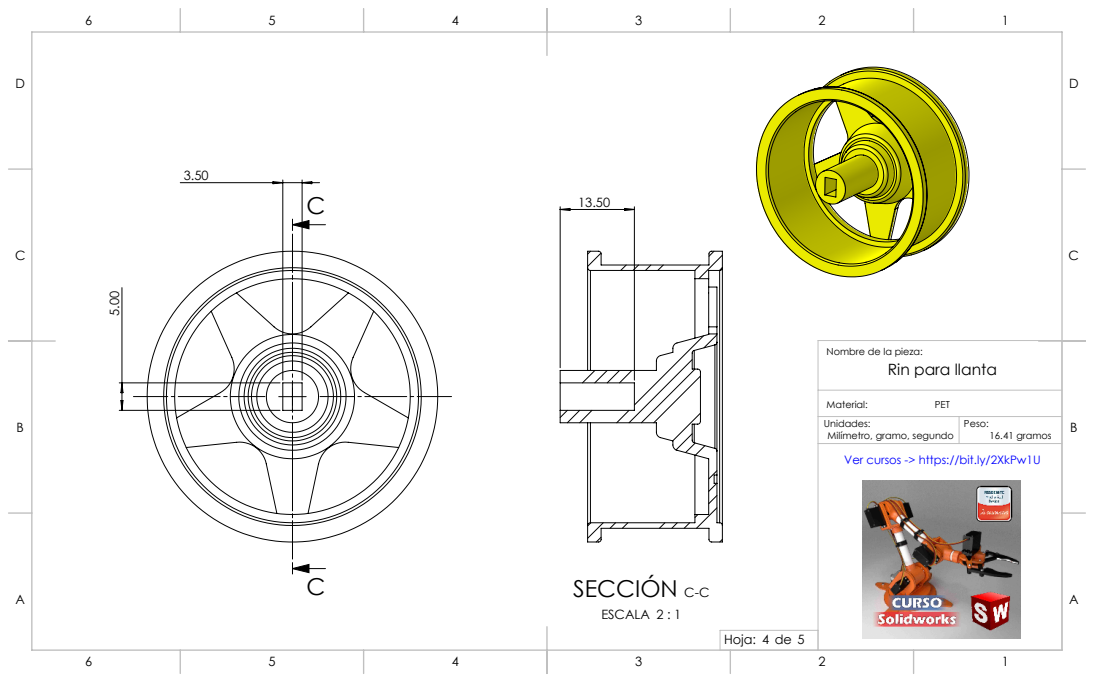
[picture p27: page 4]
SECCIÓN C-C; ESCALA 2 : 1; 16.41 gramos

Nombre de la pieza:
Rin para llanta

Milímetro, gramo, segundo
Ver cursos -> https://bit.ly/2XkPw1U

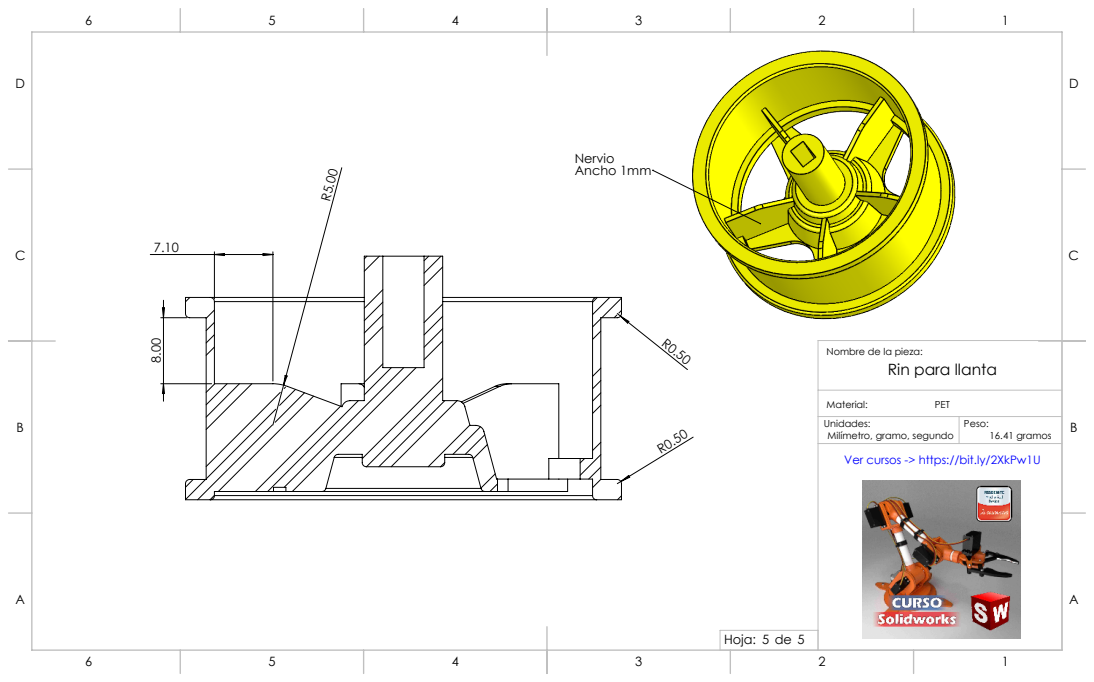
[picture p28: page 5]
Ancho 1mm; 16.41 gramos

Nombre de la pieza:
Rin para llanta

Milímetro, gramo, segundo
Ver cursos -> https://bit.ly/2XkPw1U

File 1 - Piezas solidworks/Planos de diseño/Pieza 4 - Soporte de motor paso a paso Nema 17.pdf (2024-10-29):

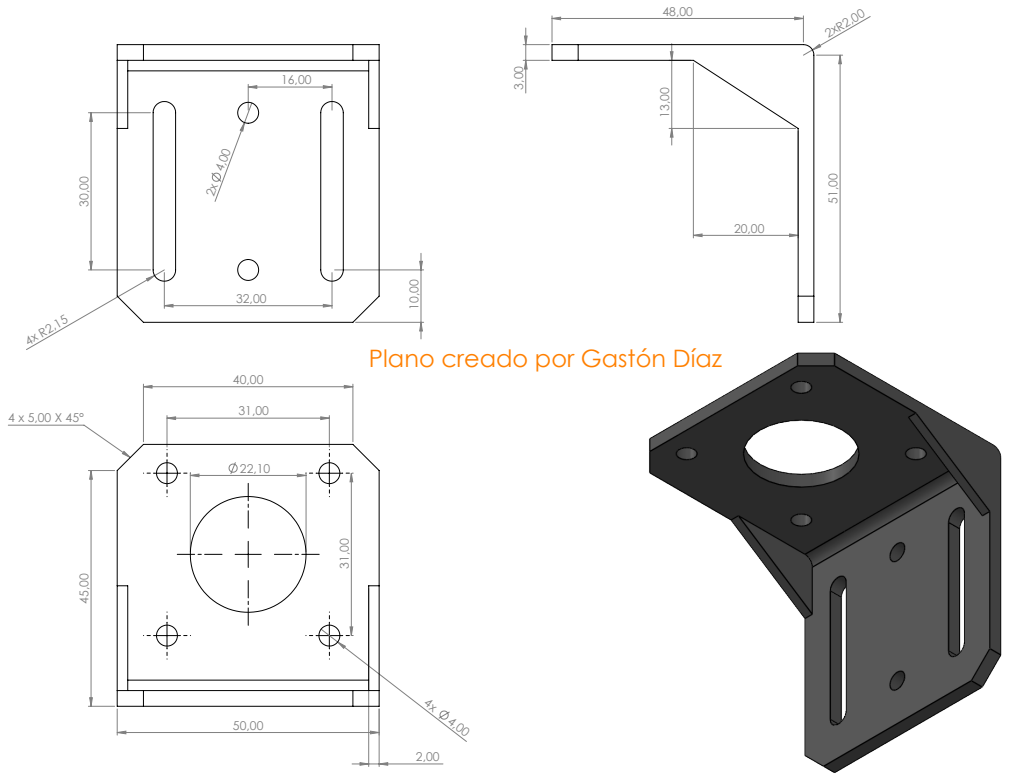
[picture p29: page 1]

Plano creado por Gastón Díaz

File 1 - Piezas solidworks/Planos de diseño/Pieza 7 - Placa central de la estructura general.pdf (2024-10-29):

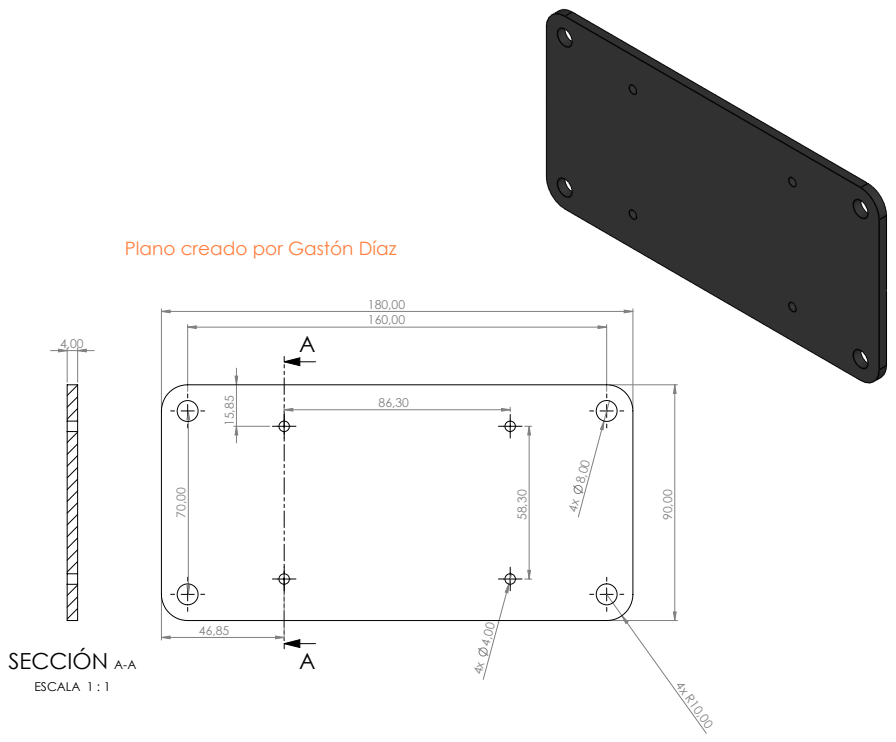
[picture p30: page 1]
SECCIÓN A-A; ESCALA 1 : 1

Plano creado por Gastón Díaz

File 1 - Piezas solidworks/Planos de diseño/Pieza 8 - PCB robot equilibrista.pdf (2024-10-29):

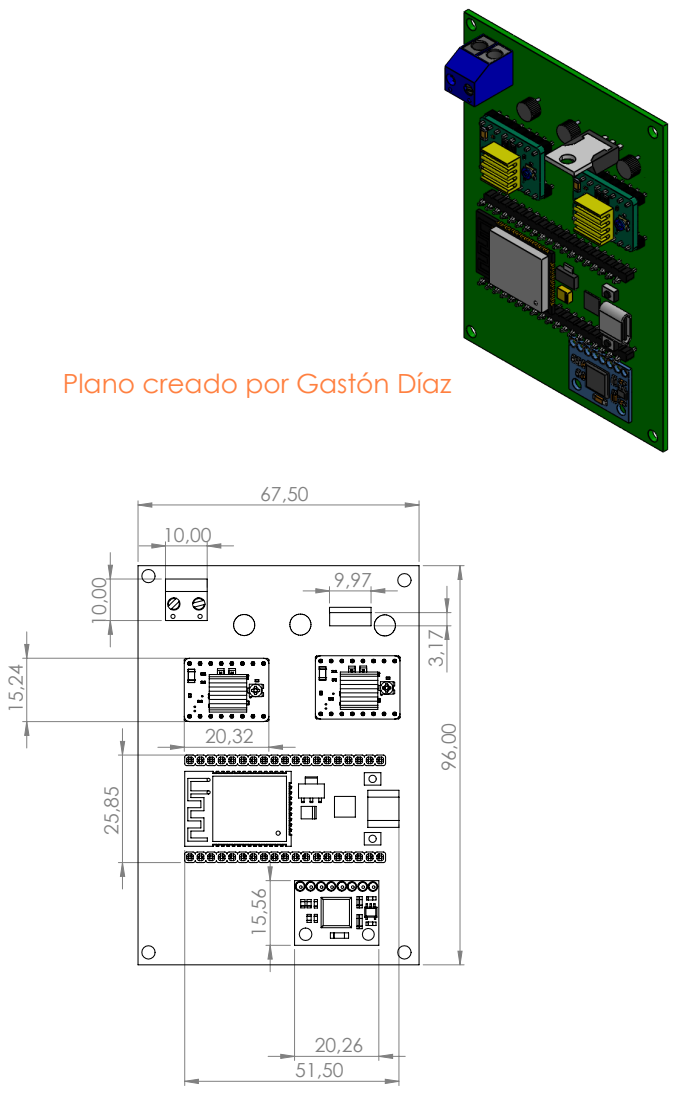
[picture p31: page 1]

Plano creado por Gastón Díaz

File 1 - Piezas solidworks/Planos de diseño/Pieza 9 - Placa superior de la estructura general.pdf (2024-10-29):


Plano creado por Gastón Díaz




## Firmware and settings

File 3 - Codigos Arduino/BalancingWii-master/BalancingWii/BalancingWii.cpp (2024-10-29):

/*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
 ########## Extended for balancing robot by Mahowik ############
 
*/

#include <avr/io.h>

#include "Arduino.h"
#include "config.h"
#include "def.h"
#include "types.h"
#include "BalancingWii.h"
#include "Alarms.h"
#include "EEPROM.h"
#include "IMU.h"
#include "LCD.h"
#include "Output.h"
#include "RX.h"
#include "Sensors.h"
#include "Serial.h"
#include "GPS.h"
#include "Protocol.h"

#include <avr/pgmspace.h>

/*********** RC alias *****************/

const char pidnames[] PROGMEM =
  "SPEED;"
  "ANGLE;"
  //"YAW;"
  "ALT;"
  "Pos;"
  "PosR;"
  "NavR;"
  //"LEVEL;"
  "MAG;"
  "VEL;"
;

const char boxnames[] PROGMEM = // names for dynamic generation of config GUI
  "ARM;"
  #if ACC
    "SIMPLE;"
    "RISE;"
    "POS HOLD;"
  #endif
  #if BARO && (!defined(SUPPRESS_BARO_ALTHOLD))
    "BARO;"
  #endif
  #ifdef VARIOMETER
    "VARIO;"
  #endif
  #if MAG
    "MAG;"
    "HEADFREE;"
    "HEADADJ;"  
  #endif
  #if defined(SERVO_TILT) || defined(GIMBAL)|| defined(SERVO_MIX_TILT)
    "CAMSTAB;"
  #endif
  #if defined(CAMTRIG)
    "CAMTRIG;"
  #endif
  #if GPS
    "GPS HOME;"
    "GPS HOLD;"
  #endif
  #if defined(FIXEDWING) || defined(HELICOPTER)
    "PASSTHRU;"
  #endif
  #if defined(BUZZER)
    "BEEPER;"
  #endif
  #if defined(LED_FLASHER)
    "LEDMAX;"
    "LEDLOW;"
  #endif
  #if defined(LANDING_LIGHTS_DDR)
    "LLIGHTS;"
  #endif
  #ifdef INFLIGHT_ACC_CALIBRATION
    "CALIB;"
  #endif
  #ifdef GOVERNOR_P
    "GOVERNOR;"
  #endif
  #ifdef OSD_SWITCH
    "OSD SW;"
  #endif
;

const uint8_t boxids[] PROGMEM = {// permanent IDs associated to boxes. This way, you can rely on an ID number to identify a BOX function.
  0, //"ARM;"
  #if ACC
    1, //"SIMPLE;"
    2, //"RISE;"
    3, //"POS HOLD;"
  #endif
  #if BARO && (!defined(SUPPRESS_BARO_ALTHOLD))
    3, //"BARO;"
  #endif
  #ifdef VARIOMETER
    4, //"VARIO;"
  #endif
  #if MAG
    5, //"MAG;"
    6, //"HEADFREE;"
    7, //"HEADADJ;"  
  #endif
  #if defined(SERVO_TILT) || defined(GIMBAL)|| defined(SERVO_MIX_TILT)
    8, //"CAMSTAB;"
  #endif
  #if defined(CAMTRIG)
    9, //"CAMTRIG;"
  #endif
  #if GPS
    10, //"GPS HOME;"
    11, //"GPS HOLD;"
  #endif
  #if defined(FIXEDWING) || defined(HELICOPTER)
    12, //"PASSTHRU;"
  #endif
  #if defined(BUZZER)
    13, //"BEEPER;"
  #endif
  #if defined(LED_FLASHER)
    14, //"LEDMAX;"
    15, //"LEDLOW;"
  #endif
  #if defined(LANDING_LIGHTS_DDR)
    16, //"LLIGHTS;"
  #endif
  #ifdef INFLIGHT_ACC_CALIBRATION
    17, //"CALIB;"
  #endif
  #ifdef GOVERNOR_P
    18, //"GOVERNOR;"
  #endif
  #ifdef OSD_SWITCH
    19, //"OSD_SWITCH;"
  #endif
};


uint32_t currentTime = 0;
uint16_t previousTime = 0;
uint16_t cycleTime = 0;     // this is the number in micro second to achieve a full loop, it can differ a little and is taken into account in the PID loop
uint16_t calibratingA = 0;  // the calibration is done in the main loop. Calibrating decreases at each cycle down to 0, then we enter in a normal mode.
uint16_t calibratingB = 0;  // baro calibration = get new ground pressure value
uint16_t calibratingG;
int16_t  magHold,headFreeModeHold; // [-180;+180]
uint8_t  vbatMin = VBATNOMINAL;  // lowest battery voltage in 0.1V steps
uint8_t  rcOptions[CHECKBOXITEMS];
int32_t  AltHold; // in cm
int16_t  sonarAlt;
int16_t  BaroPID = 0;
int16_t  errorAltitudeI = 0;

// **************
// gyro+acc IMU
// **************
int16_t gyroZero[3] = {0,0,0};

imu_t imu;

analog_t analog;

alt_t alt;

att_t att;

#if defined(ARMEDTIMEWARNING)
  uint32_t  ArmedTimeWarningMicroSeconds = 0;
#endif

int16_t  debug[4];

flags_struct_t f;

//for log
#if defined(LOG_VALUES) || defined(LCD_TELEMETRY)
  uint16_t cycleTimeMax = 0;       // highest ever cycle timen
  uint16_t cycleTimeMin = 65535;   // lowest ever cycle timen
  int32_t  BAROaltMax;             // maximum value
  uint16_t GPS_speedMax = 0;       // maximum speed from gps
  uint16_t powerValueMaxMAH = 0;
#endif
#if defined(LOG_VALUES) || defined(LCD_TELEMETRY) || defined(ARMEDTIMEWARNING) || defined(LOG_PERMANENT)
  uint32_t armedTime = 0;
#endif

int16_t  i2c_errors_count = 0;
int16_t  annex650_overrun_count = 0;



#if defined(THROTTLE_ANGLE_CORRECTION)
  int16_t throttleAngleCorrection = 0;	// correction of throttle in lateral wind,
  int8_t  cosZ = 100;					// cos(angleZ)*100
#endif



// **********************
//Automatic ACC Offset Calibration
// **********************
#if defined(INFLIGHT_ACC_CALIBRATION)
  uint16_t InflightcalibratingA = 0;
  int16_t AccInflightCalibrationArmed;
  uint16_t AccInflightCalibrationMeasurementDone = 0;
  uint16_t AccInflightCalibrationSavetoEEProm = 0;
  uint16_t AccInflightCalibrationActive = 0;
#endif

// **********************
// power meter
// **********************
#if defined(POWERMETER) || ( defined(LOG_VALUES) && (LOG_VALUES >= 3) )
  uint32_t pMeter[PMOTOR_SUM + 1];  // we use [0:7] for eight motors,one extra for sum
  uint8_t pMeterV;                  // dummy to satisfy the paramStruct logic in ConfigurationLoop()
  uint32_t pAlarm;                  // we scale the eeprom value from [0:255] to this value we can directly compare to the sum in pMeter[6]
  uint16_t powerValue = 0;          // last known current
#endif
uint16_t intPowerTrigger1;

// **********************
// telemetry
// **********************
#if defined(LCD_TELEMETRY)
  uint8_t telemetry = 0;
  uint8_t telemetry_auto = 0;
#endif
#ifdef LCD_TELEMETRY_STEP
  char telemetryStepSequence []  = LCD_TELEMETRY_STEP;
  uint8_t telemetryStepIndex = 0;
#endif

// ******************
// rc functions
// ******************
#define ROL_LO  (1<<(2*ROLL))
#define ROL_CE  (3<<(2*ROLL))
#define ROL_HI  (2<<(2*ROLL))
#define PIT_LO  (1<<(2*PITCH))
#define PIT_CE  (3<<(2*PITCH))
#define PIT_HI  (2<<(2*PITCH))
#define YAW_LO  (1<<(2*YAW))
#define YAW_CE  (3<<(2*YAW))
#define YAW_HI  (2<<(2*YAW))
#define THR_LO  (1<<(2*THROTTLE))
#define THR_CE  (3<<(2*THROTTLE))
#define THR_HI  (2<<(2*THROTTLE))

#define LED_FRENTE A0    // LED para ambos motores adelante
#define LED_ATRAS A1     // LED para ambos motores atrás
#define LED_DERECHA A2   // LED para motor 1 derecha y motor 2 izquierda
#define LED_IZQUIERDA A3  // LED para motor 1 izquierda y motor 2 derecha

int16_t failsafeEvents = 0;
volatile int16_t failsafeCnt = 0;

int16_t rcData[RC_CHANS];    // interval [1000;2000]
int16_t rcSerial[8];         // interval [1000;2000] - is rcData coming from MSP
int16_t rcCommand[4];        // interval [1000;2000] for THROTTLE and [-500;+500] for ROLL/PITCH/YAW
uint8_t rcSerialCount = 0;   // a counter to select legacy RX when there is no more MSP rc serial data
int16_t lookupPitchRollRC[5];// lookup table for expo & RC rate PITCH+ROLL
int16_t lookupThrottleRC[11];// lookup table for expo & mid THROTTLE

#if defined(SPEKTRUM)
  volatile uint8_t  spekFrameFlags;
  volatile uint32_t spekTimeLast;
#endif

#if defined(OPENLRSv2MULTI)
  uint8_t pot_P,pot_I; // OpenLRS onboard potentiometers for P and I trim or other usages
#endif


// *************************
// motor and servo functions
// *************************
//int16_t output;
int16_t motor[2];
//int16_t servo[8] = {1500,1500,1500,1500,1500,1500,1500,1000};

int16_t actualMotorSpeed[2];     // actual speed of motors
uint8_t actualMotorDir[2];       // actual direction of steppers motors

int16_t actualSpeed;     // actual speed of robot

// ************************
// EEPROM Layout definition
// ************************
static uint8_t dynP8[2], dynD8[2];

global_conf_t global_conf;

conf_t conf;

#ifdef LOG_PERMANENT
  plog_t plog;
#endif

// **********************
// GPS common variables
// **********************
  int16_t  GPS_angle[2] = { 0, 0};                      // the angles that must be applied for GPS correction
  int32_t  GPS_coord[2];
  int32_t  GPS_home[2];
  int32_t  GPS_hold[2];
  uint8_t  GPS_numSat;
  uint16_t GPS_distanceToHome;                          // distance to home  - unit: meter
  int16_t  GPS_directionToHome;                         // direction to home - unit: degree
  uint16_t GPS_altitude;                                // GPS altitude      - unit: meter
  uint16_t GPS_speed;                                   // GPS speed         - unit: cm/s
  uint8_t  GPS_update = 0;                              // a binary toogle to distinct a GPS position update
  uint16_t GPS_ground_course = 0;                       //                   - unit: degree*10
  uint8_t  GPS_Present = 0;                             // Checksum from Gps serial
  uint8_t  GPS_Enable  = 0;

  // The desired bank towards North (Positive) or South (Negative) : latitude
  // The desired bank towards East (Positive) or West (Negative)   : longitude
  int16_t  nav[2];
  int16_t  nav_rated[2];    //Adding a rate controller to the navigation to make it smoother

  uint8_t nav_mode = NAV_MODE_NONE; // Navigation mode

  uint8_t alarmArray[16];           // array
 
#if BARO
  int32_t baroPressure;
  int32_t baroTemperature;
  int32_t baroPressureSum;
#endif
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
void loop () {
  static uint8_t rcDelayCommand; // this indicates the number of time (multiple of RC measurement at 50Hz) the sticks must be maintained to run or switch off motors
  static uint8_t rcSticks;       // this hold sticks position for command combos
  uint8_t axis,i;
  int16_t error;
//  int16_t delta;
//  int16_t PTerm = 0,ITerm = 0,DTerm;//, PTermACC, ITermACC;
  //static int16_t lastGyro[2] = {0,0};
  static int16_t angleErrorI = 0, speedErrorI = 0;

//#if PID_CONTROLLER == 1
//  static int32_t errorGyroI_YAW;
//  static int16_t delta1[2],delta2[2];
//  static int16_t errorGyroI[2] = {0,0};
//#elif PID_CONTROLLER == 2
//  static int16_t delta1[3],delta2[3];
//  static int32_t errorGyroI[3] = {0,0,0};
//  static int16_t lastError[3] = {0,0,0};
//  int16_t deltaSum;
//  int16_t AngleRateTmp, RateError;
//#endif
  static uint32_t rcTime  = 0;
  static int16_t initialThrottleHold;
  static uint32_t timestamp_fixated = 0;
  int16_t rc;
  int32_t prop = 0;

  #if defined(SPEKTRUM)
    if (spekFrameFlags == 0x01) readSpektrum();
  #endif
  
  #if defined(OPENLRSv2MULTI) 
    Read_OpenLRS_RC();
  #endif 

  if (currentTime > rcTime ) { // 50Hz
    rcTime = currentTime + 20000;
    computeRC();
    // Failsafe routine - added by MIS
    #if defined(FAILSAFE)
      if ( failsafeCnt > (5*FAILSAFE_DELAY) && f.ARMED) {                  // Stabilize, and set Throttle to specified level
        for(i=0; i<3; i++) rcData[i] = MIDRC;                               // after specified guard time after RC signal is lost (in 0.1sec)
        rcData[THROTTLE] = conf.failsafe_throttle;
        if (failsafeCnt > 5*(FAILSAFE_DELAY+FAILSAFE_OFF_DELAY)) {          // Turn OFF motors after specified Time (in 0.1sec)
          go_disarm();     // This will prevent the copter to automatically rearm if failsafe shuts it down and prevents
          f.OK_TO_ARM = 0; // to restart accidentely by just reconnect to the tx - you will have to switch off first to rearm
        }
        failsafeEvents++;
      }
      if ( failsafeCnt > (5*FAILSAFE_DELAY) && !f.ARMED) {  //Turn of "Ok To arm to prevent the motors from spinning after repowering the RX with low throttle and aux to arm
          go_disarm();     // This will prevent the copter to automatically rearm if failsafe shuts it down and prevents
          f.OK_TO_ARM = 0; // to restart accidentely by just reconnect to the tx - you will have to switch off first to rearm
      }
      failsafeCnt++;
    #endif
    // end of failsafe routine - next change is made with RcOptions setting

    // ------------------ STICKS COMMAND HANDLER --------------------
    // checking sticks positions
    uint8_t stTmp = 0;
    for(i=0;i<4;i++) {
      stTmp >>= 2;
      if(rcData[i] > MINCHECK) stTmp |= 0x80;      // check for MIN
      if(rcData[i] < MAXCHECK) stTmp |= 0x40;      // check for MAX
    }
    if(stTmp == rcSticks) {
      if(rcDelayCommand<250) rcDelayCommand++;
    } else rcDelayCommand = 0;
    rcSticks = stTmp;
    
    // perform actions    
    if (rcData[THROTTLE] <= MINCHECK) {            // THROTTLE at minimum
      #if !defined(FIXEDWING)
        //errorGyroI[ROLL] = 0; errorGyroI[PITCH] = 0;
        #if PID_CONTROLLER == 1
          errorGyroI_YAW = 0;
        #elif PID_CONTROLLER == 2
          errorGyroI[YAW] = 0;
        #endif
        //angleErrorI[ROLL] = 0; angleErrorI[PITCH] = 0;
      #endif
      //if (conf.activate[BOXARM] > 0) {             // Arming/Disarming via ARM BOX
      //  if ( rcOptions[BOXARM] && f.OK_TO_ARM ) go_arm(); else if (f.ARMED) go_disarm();
      //}
    }
    
    if (conf.activate[BOXARM] > 0) {             // Arming/Disarming via ARM BOX
      if ( rcOptions[BOXARM] && f.OK_TO_ARM ) go_arm(); else if (f.ARMED) go_disarm();
    }
    
    if(rcDelayCommand == 20) {
      if(f.ARMED) {                   // actions during armed
        #ifdef ALLOW_ARM_DISARM_VIA_TX_YAW
          if (conf.activate[BOXARM] == 0 && rcSticks == THR_LO + YAW_LO + PIT_CE + ROL_CE) go_disarm();    // Disarm via YAW
        #endif
        #ifdef ALLOW_ARM_DISARM_VIA_TX_ROLL
          if (conf.activate[BOXARM] == 0 && rcSticks == THR_LO + YAW_CE + PIT_CE + ROL_LO) go_disarm();    // Disarm via ROLL
        #endif
      } else {                        // actions during not armed
        i=0;
        if (rcSticks == THR_LO + YAW_LO + PIT_LO + ROL_CE) {    // GYRO calibration
          calibratingG=512;
          #if GPS 
            GPS_reset_home_position();
          #endif
          #if BARO
            calibratingB=10;  // calibrate baro to new ground level (10 * 25 ms = ~250 ms non blocking)
          #endif
        }
        #if defined(INFLIGHT_ACC_CALIBRATION)  
         else if (rcSticks == THR_LO + YAW_LO + PIT_HI + ROL_HI) {    // Inflight ACC calibration START/STOP
            if (AccInflightCalibrationMeasurementDone){                // trigger saving into eeprom after landing
              AccInflightCalibrationMeasurementDone = 0;
              AccInflightCalibrationSavetoEEProm = 1;
            }else{ 
              AccInflightCalibrationArmed = !AccInflightCalibrationArmed; 
              #if defined(BUZZER)
               if (AccInflightCalibrationArmed) alarmArray[0]=2; else   alarmArray[0]=3;
              #endif
            }
         } 
        #endif
        #ifdef MULTIPLE_CONFIGURATION_PROFILES
          if      (rcSticks == THR_LO + YAW_LO + PIT_CE + ROL_LO) i=1;    // ROLL left  -> Profile 1
          else if (rcSticks == THR_LO + YAW_LO + PIT_HI + ROL_CE) i=2;    // PITCH up   -> Profile 2
          else if (rcSticks == THR_LO + YAW_LO + PIT_CE + ROL_HI) i=3;    // ROLL right -> Profile 3
          if(i) {
            global_conf.currentSet = i-1;
            writeGlobalSet(0);
            readEEPROM();
            blinkLED(2,40,i);
            alarmArray[0] = i;
          }
        #endif
        if (rcSticks == THR_LO + YAW_HI + PIT_HI + ROL_CE) {            // Enter LCD config
          #if defined(LCD_CONF)
            configurationLoop(); // beginning LCD configuration
          #endif
          previousTime = micros();
        }
        #ifdef ALLOW_ARM_DISARM_VIA_TX_YAW
          else if (conf.activate[BOXARM] == 0 && rcSticks == THR_LO + YAW_HI + PIT_CE + ROL_CE) go_arm();      // Arm via YAW
        #endif
        #ifdef ALLOW_ARM_DISARM_VIA_TX_ROLL
          else if (conf.activate[BOXARM] == 0 && rcSticks == THR_LO + YAW_CE + PIT_CE + ROL_HI) go_arm();      // Arm via ROLL
        #endif
        #ifdef LCD_TELEMETRY_AUTO
          else if (rcSticks == THR_LO + YAW_CE + PIT_HI + ROL_LO) {              // Auto telemetry ON/OFF
            if (telemetry_auto) {
              telemetry_auto = 0;
              telemetry = 0;
            } else
              telemetry_auto = 1;
          }
        #endif
        #ifdef LCD_TELEMETRY_STEP
          else if (rcSticks == THR_LO + YAW_CE + PIT_HI + ROL_HI) {              // Telemetry next step
            telemetry = telemetryStepSequence[++telemetryStepIndex % strlen(telemetryStepSequence)];
            #if defined( OLED_I2C_128x64)
              if (telemetry != 0) i2c_OLED_init();
            #elif defined(OLED_DIGOLE)
              if (telemetry != 0) i2c_OLED_DIGOLE_init();
            #endif
            LCDclear();
          }
        #endif
        #if ACC
          else if (rcSticks == THR_HI + YAW_LO + PIT_LO + ROL_CE) calibratingA=512;     // throttle=max, yaw=left, pitch=min
        #endif
        #if MAG
          else if (rcSticks == THR_HI + YAW_HI + PIT_LO + ROL_CE) f.CALIBRATE_MAG = 1;  // throttle=max, yaw=right, pitch=min
        #endif
        i=0;
        if      (rcSticks == THR_HI + YAW_CE + PIT_HI + ROL_CE) {conf.angleTrim[PITCH]+=2; i=1;}
        else if (rcSticks == THR_HI + YAW_CE + PIT_LO + ROL_CE) {conf.angleTrim[PITCH]-=2; i=1;}
        else if (rcSticks == THR_HI + YAW_CE + PIT_CE + ROL_HI) {conf.angleTrim[ROLL] +=2; i=1;}
        else if (rcSticks == THR_HI + YAW_CE + PIT_CE + ROL_LO) {conf.angleTrim[ROLL] -=2; i=1;}
        if (i) {
          writeParams(1);
          rcDelayCommand = 0;    // allow autorepetition
          #if defined(LED_RING)
            blinkLedRing();
          #endif
        }
      }
    }
    #if defined(LED_FLASHER)
      led_flasher_autoselect_sequence();
    #endif
    
    #if defined(INFLIGHT_ACC_CALIBRATION)
      if (AccInflightCalibrationArmed && f.ARMED && rcData[THROTTLE] > MINCHECK && !rcOptions[BOXARM] ){ // Copter is airborne and you are turning it off via boxarm : start measurement
        InflightcalibratingA = 50;
        AccInflightCalibrationArmed = 0;
      }  
      if (rcOptions[BOXCALIB]) {      // Use the Calib Option to activate : Calib = TRUE Meausrement started, Land and Calib = 0 measurement stored
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

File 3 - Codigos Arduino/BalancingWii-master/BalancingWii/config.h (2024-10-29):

#ifndef CONFIG_H_
#define CONFIG_H_

/*************************************************************************************************/
/****           CONFIGURABLE PARAMETERS                                                       ****/
/*************************************************************************************************/

/* this file consists of several sections
 * to create a working combination you must at least make your choices in section 1.
 * 1 - BASIC SETUP - you must select an option in every block.
 *      this assumes you have 4 channels connected to your board with standard ESCs and servos.
 * 2 - COPTER TYPE SPECIFIC OPTIONS - you likely want to check for options for your copter type
 * 3 - RC SYSTEM SETUP
 * 4 - ALTERNATE CPUs & BOARDS - if you have
 * 5 - ALTERNATE SETUP - select alternate RX (SBUS, PPM, etc.), alternate ESC-range, etc. here
 * 6 - OPTIONAL FEATURES - enable nice to have features here (FlightModes, LCD, telemetry, battery monitor etc.)
 * 7 - TUNING & DEVELOPER - if you know what you are doing; you have been warned
 *     - (ESCs calibration, Dynamic Motor/Prop Balancing, Diagnostics,Memory savings.....)
 * 8 - DEPRECATED - these features will be removed in some future release
 */

/* Notes:
 * 1. parameters marked with (*) in the comment are stored in eeprom and can be changed via serial monitor or LCD.
 * 2. parameters marked with (**) in the comment are stored in eeprom and can be changed via the GUI
 */


/*************************************************************************************************/
/*****************                                                                 ***************/
/****************  SECTION  1 - BASIC SETUP                                                *******/
/*****************                                                                 ***************/
/*************************************************************************************************/
    
    #define CURRENT_AXIS    PITCH       // possible to choose ROLL or PITCH axis as current.
    
    //#define INVERT_CURRENT_AXIS       // invert current axis sign, i.e. instead of turning sensor board
    
    //#define REVERSE_MOTORS_DIRECTION  // reverse both motors direction

    #define MAX_SPEED           350  // should be <= 500 // Con 350 va bien 
    #define MAX_TARGET_ANGLE    130  // where 10 = 1 degree, should be <= 15 degree (i.e. <= 150) 
    #define MAX_STEERING        90   // should be <= 100
	
    #define RISE_SPEED_K		1.0f // this coefficient means how faster robot will be during the auto rising...  should be >= 0.5 but <= 2.0
    

  /****************************    Motor minthrottle    *******************************/
    /* Set the minimum throttle command sent to the ESC (Electronic Speed Controller)
       This is the minimum value that allow motors to run at a idle speed  */
    //#define MINTHROTTLE 1300 // for Turnigy Plush ESCs 10A
    //#define MINTHROTTLE 1120 // for Super Simple ESCs 10A
    //#define MINTHROTTLE 1064 // special ESC (simonk)
    //#define MINTHROTTLE 1050 // for brushed ESCs like ladybird
    #define MINTHROTTLE 1100 // (*)

  /****************************    Motor maxthrottle    *******************************/
    /* this is the maximum value for the ESCs at full power, this value can be increased up to 2000 */
    #define MAXTHROTTLE 1900

  /****************************    Mincommand          *******************************/
    /* this is the value for the ESCs when they are not armed
       in some cases, this value must be lowered down to 900 for some specific ESCs, otherwise they failed to initiate */
    #define MINCOMMAND  1000

  /**********************************  I2C speed for old WMP config (useless config for other sensors)  *************/
    //#define I2C_SPEED 100000L     //100kHz normal mode, this value must be used for a genuine WMP
    #define I2C_SPEED 400000L   //400kHz fast mode, it works only with some WMP clones

  /***************************    Internal i2c Pullups   ********************************/
    /* enable internal I2C pull ups (in most cases it is better to use external pullups) */
    #define INTERNAL_I2C_PULLUPS

  /**************************************************************************************/
  /*****************          boards and sensor definitions            ******************/
  /**************************************************************************************/
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

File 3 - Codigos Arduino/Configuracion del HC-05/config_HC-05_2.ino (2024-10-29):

#include <SoftwareSerial.h>  // Incluimos la librería  SoftwareSerial  
SoftwareSerial BT(10,11);    // Definimos del Arduino conectados al Bluetooth

void setup()
{
  Serial.begin(9600);   // Inicializamos  el puerto serie  
  Serial.println("Listo");
  BT.begin(38400);      // Inicializamos el puerto serie BT (Para Modo AT 2)
}
 
void loop()
{
  if(BT.available())    // Si llega un dato por el puerto BT se envía al monitor serial
  {
    Serial.write(BT.read());    // Lee BT y  envia a arduino
  }
 
  if(Serial.available())  // Si llega un dato por el monitor serial se envía al puerto BT
  {
     BT.write(Serial.read()); // Lee arduino y envia a BT
  }
}

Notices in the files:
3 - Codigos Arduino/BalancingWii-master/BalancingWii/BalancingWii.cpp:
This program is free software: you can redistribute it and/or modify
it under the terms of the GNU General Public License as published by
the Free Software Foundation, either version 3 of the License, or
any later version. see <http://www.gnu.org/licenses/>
